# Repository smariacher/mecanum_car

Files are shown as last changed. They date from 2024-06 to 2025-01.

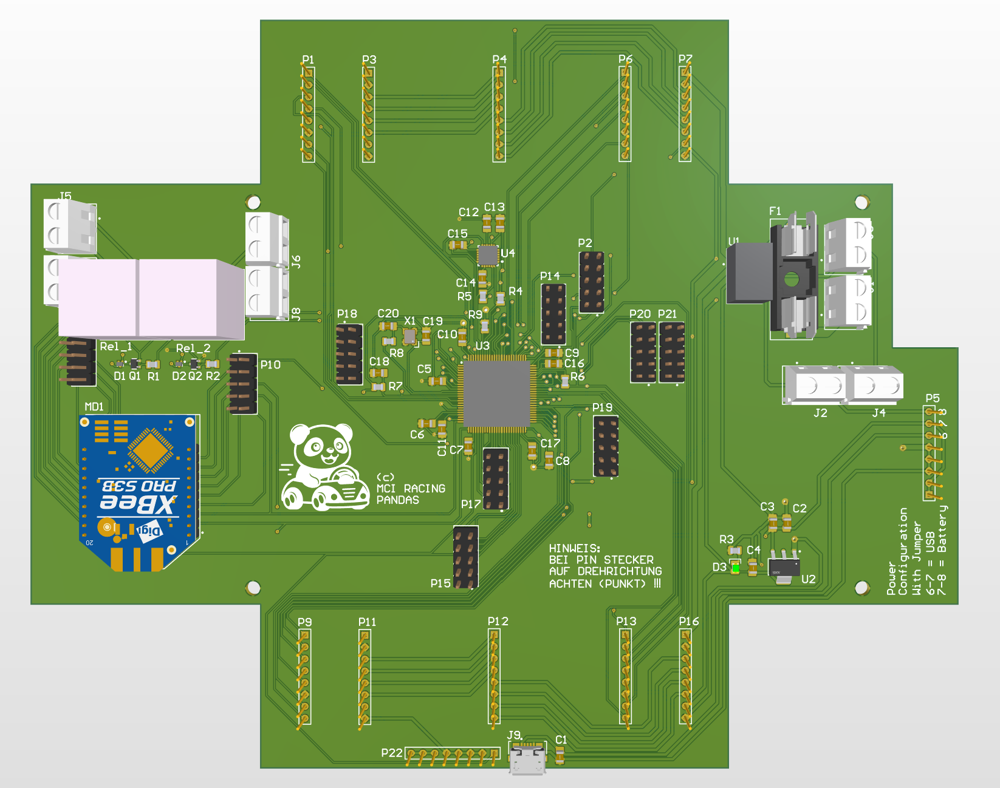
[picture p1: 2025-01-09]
Schematics/mecanum_car_2D.png

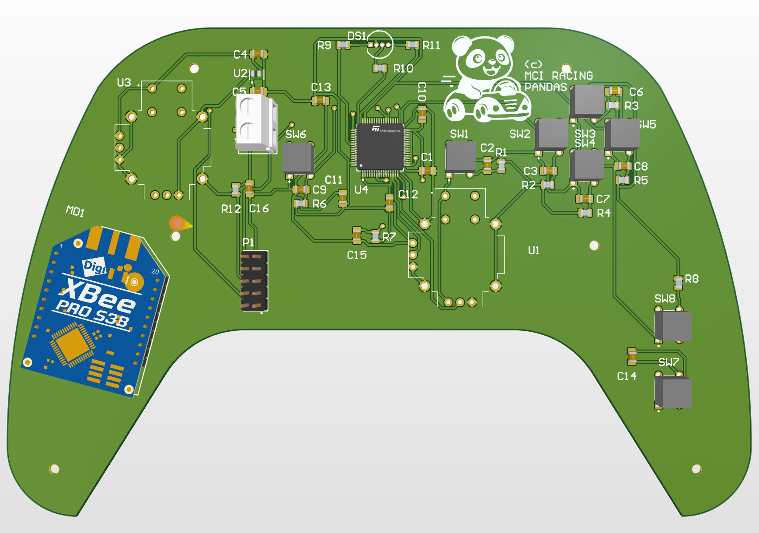
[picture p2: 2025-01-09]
Schematics/mecanum_car_controller_2D.png

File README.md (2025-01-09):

Mecanum Car Project

This repository contains all files and documentation related to the Mecanum Car, developed over two semesters (4th and 5th semester) as part of the Bachelor's degree program in Mechatronics Design & Innovation. The goal of the project was to design, implement, and test a fully functional Mecanum Car that meets both mechanical and electronic requirements.
Project Overview

The project's objective was to develop a functional Mecanum Car with omnidirectional movement capabilities. The focus was on mechanical design, electronic development, and software integration. The work spanned two semesters to allow iterative improvement and extension.
Key Features
Mechanical Design

    Lightweight and robust aluminum chassis for high durability and stability.
    Protective housing for all electronic components.
    Use of Mecanum wheels for omnidirectional movement.

Electronic System

    Power supply via a Makita power drill battery with an integrated voltage converter.
    Control unit based on an STM32F401VET6 microcontroller, offering sufficient reserves for future expansions.
    Integration of a gyro sensor (MPU6050) for acceleration data acquisition.
    Communication modules (XBee, infrared receiver) for future remote control options.
    Wiring of LEDs for front (white) and rear (red) lighting.

Software

    Control via Xbox controller.
    Debugging functionalities through hardware buttons.
    Modular programming of basic functions with potential for further extension.

Extensions

    Design and production of a custom controller PCB.
    Installation of a fan for cooling the PCB and motor drivers.
    Wiring and mounting of LEDs for vehicle lighting.

Repository Contents

    Mechanical Designs: CAD files of vehicle components (base plate, motor mounts, bumpers, etc.).
    Electronics: Schematics and PCB layouts created with Altium Designer.
    Firmware: Control software for the Mecanum Car, written in C++ for the STM32 microcontroller.
    Documentation: Final reports, technical specifications, and user manuals.

Getting Started
Prerequisites

    Development Environment:
        Altium Designer for PCB design.
        Visual Studio Code for firmware development.
    Hardware:
        Mecanum wheels, stepper motors, Makita battery, STM32 microcontroller, gyro sensor, and other components.

Installation

    Clone the repository:

    git clone https://github.com/smariacher/mecanum_car.git

    Open the project files in the corresponding software tools.

    Compile the firmware using the STM32 development environment.

Current Status

    Mechanics: The chassis has been fully implemented and functions flawlessly.
    Electronics: The PCB and motor control systems are fully operational.
    Software: Basic motion functionalities have been implemented; advanced features are under development.

Future Work

    Optimization of motor drivers for improved performance.
    Integration of a display for sensor data visualization.
    Expansion of automation and control functionalities.

Contributors

    Julian Fritzer
    Patrick Monthaler
    Simon Mariacher

## Source code
#### General Overview
Inside the `source_code` folder you can find the main code, the python controller and the example folder. The main code is meant to be flashed to the car and is the current working version. The python controller can be used to control the car via a computer using for example an Xbox-Controller or just keyboard inputs. Inside the `examples` folder you can find examples for XBEE-connection to the car, driving the stepper motors and more. There is also the old source code 

#### Main source code
The main source code has been thoroughly documented and can be flashed to the car via the exposed USB-B port on the side. For this you will need `Platform IO` in `Visual Studio Code`. 

#### Python Controller
To use the python controller, you will need to connect an XBEE via USB to your PC and configure the script to use the right COM port. You will also need to install `pygame`. When connecting a controller the code will automatically detect it when starting up and use the controller as input. When no controller is connected it will use the keyboard buttons WASD+EQ for movement and f+b for front and backlight respectively. The space bar is set to be used as an emergency stop function, where all motors will be disabled (meaning the will move freely) so that the car comes to a smooth stop. After emergency stopping you have to reset the car via the connected external button. Using a controller the car is moved through both analog sticks, and the A-Button is used as emergency stop (when using a XBOX-Controller).

#### Wireless protocol
The car's controller listens to UART2 which is connected to the XBEE. On receiving a message an interrupt function is called, which either changes the wheel speeds, toggles front or backlight or intitiates emergency stop. The message protocol to controll the wheel speeds is simple and consists of 20 characters, 5 for each wheel where the step frequency for the wheel is defined. As an example you can send a message using a tool like `PuTTY` and send `01000010000100001000` which will move every wheel at 1000 speed. Of course this protocol is limited to a max speed of 99999 or -9999. This should be upgraded later on.

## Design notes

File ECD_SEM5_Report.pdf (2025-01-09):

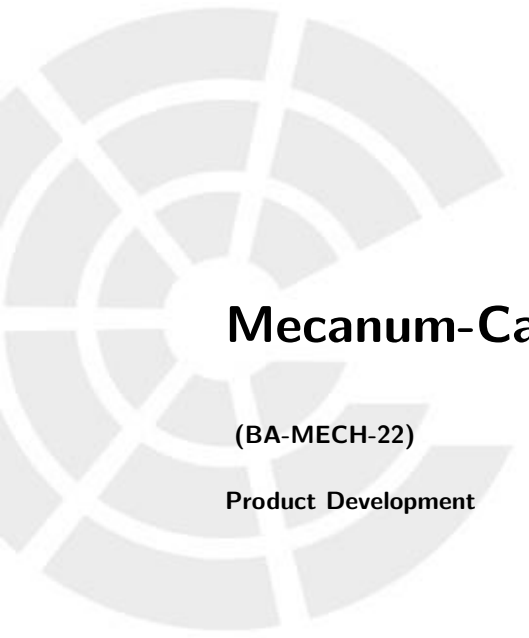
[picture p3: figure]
(BA-MECH-22); Product Development

# Mecanum-Car Report 5.Semester

Bachelor - Mechatronik Design & Innovation

### 5. Semester

Lektor: Matthias Gfall

Gruppe: BA-MECH-22

Autoren: Julian Fritzer, Patrick Monthaler, Simon Mariacher

### 9. Januar 2025

# Inhaltsverzeichnis

1 Abstract | 1
2 Introduction | 1
3 Equipment and Tools | 2
4 Project Objectives | 2
5 Methodology | 3
6 Discussion | 5
7 Conclusion and Future Work | 5
Abbildungsverzeichnis | III
Literaturverzeichnis | IV

II

2 INTRODUCTION

# 1 Abstract

This report presents the development of a Mecanum-Car over two semesters as part of the Bachelor’s program in Mechatronics Design and Innovation. The project combines mechanical design, electronic systems, and software integration to create a fully functional car with omnidirectional movement capabilities. The following sections detail the objectives, methods, and results, highlighting challenges and future potential for optimization.

# 2 Introduction

The Mecanum-Car project 2.1 was undertaken during the 4th and 5th semesters to integrate theoretical and practical aspects of mechatronic systems. The car uses Mecanum wheels to achieve omnidirectional movement, enabling precise control in confined spaces. The project included mechanical design, electronic system development, and software integration. This report documents the design process, implementation steps, and outcomes.

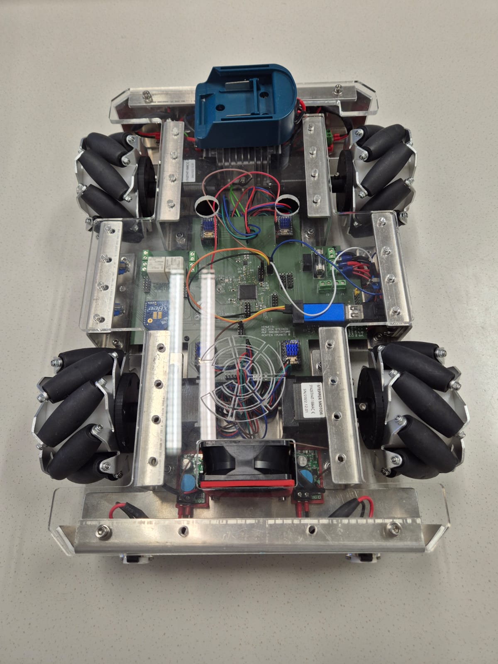
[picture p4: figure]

Abbildung 2.1: Robot with Mecanum wheels

4 PROJECT OBJECTIVES

# 3 Equipment and Tools

### 3.1 MECHANICAL COMPONENTS

- Lightweight aluminum chassis for durability and stability.
- Mecanum wheels for omnidirectional movement.
- Protective housing for electronic components.
- Air cooling system for the circuit board and motor drivers

### 3.2 ELECTRONIC COMPONENTS

- STM32F401VET6 microcontroller for control unit.
- Makita power drill battery with integrated voltage converter.
- Gyro sensor (MPU6050) for acceleration data acquisition.
- Communication modules: XBee.
- LEDs for front (white) and rear (red) lighting.

### 3.3 SOFTWARE TOOLS

- Altium Designer for PCB design.
- PlatformIO with Visual Studio Code for firmware development.
- Python and Pygame for external controller.

# 4 Project Objectives

The primary goal was to develop a fully functional Mecanum-Car with the following key features:

- Achieve omnidirectional movement through precise motor control.
- Implement a power supply system based on a Makita battery.
- Develop a custom PCB for motor control and integrate additional components like LEDs and fans.
- Enable control via an Xbox controller, a PC, and a custom-made controller, and provide debugging functionality through hardware buttons.

5 METHODOLOGY

# 5 Methodology

### 5.1 MECHANICAL DESIGN

The chassis was designed to be lightweight yet robust. Aluminum was chosen for its strength-to-weight ratio. A protective housing was included to safeguard the electronics from external damage.

Additionally, an appealing Plexiglas cover featuring an MCI logo was installed to provide a clear view of the circuit board and the internal components of the robot, enhancing its aesthetic appeal.

A fan was mounted at the front of the vehicle to ensure adequate cooling of the electronic components??.

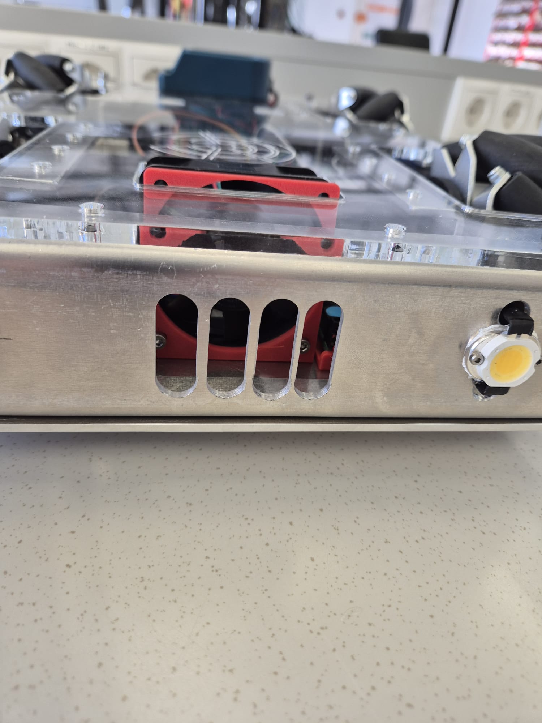
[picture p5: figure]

Abbildung 5.1: Air cooling

Mounts for controlling the front and rear LEDs were also designed and manufactured using a 3D printer. Environmentally friendly PLA material was used for this purpose ??.

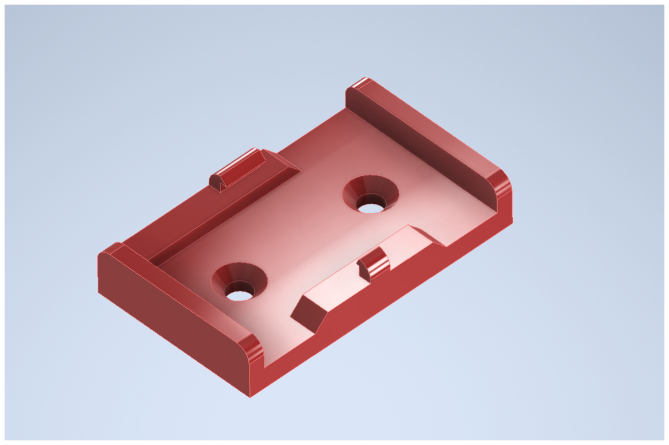
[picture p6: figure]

Abbildung 5.2: LED control fixture

5.2 Electronic System | 5 METHODOLOGY

### 5.2 ELECTRONIC SYSTEM

The control unit was based on the STM32F401VET6 microcontroller, offering sufficient capacity for future expansions. A Makita battery provided the primary power supply, ensuring reliable performance. Communication modules (XBee and infrared receiver) were integrated for wireless control. Cooling systems, including a fan, were added to maintain component performance.

The entire project was extended with a custom-designed controller that utilizes XBEE transmission. The controller is powered by three AAA batteries. The design was carefully crafted to ensure both ergonomic handling and a familiar look and feel, resembling a traditional console controller.


Abbildung 5.3: Mecanum car controller

The entire vehicle was rewired and enhanced with front and rear LEDs, including their corresponding control systems.

### 5.3 SOFTWARE DEVELOPMENT

Firmware was written in C++ and flashed onto the microcontroller using PlatformIO. Python scripts enabled external control via an Xbox controller. The communication protocol used UART2 to handle motor speed adjustments, lighting toggling, and emergency stops. Debugging functionalities were implemented via hardware buttons.

7 CONCLUSION AND FUTURE WORK

# 6 Discussion

The project highlighted the importance of iterative design and testing. While most objectives were achieved, certain challenges, such as optimizing motor driver performance, remain. The modular design allows for future enhancements, including sensor integration and advanced automation features.

Unfortunately, during the prototype development, a short circuit damaged the microcontroller. However, lessons were learned from this mistake. A new microcontroller was installed, and a complete circuit board diagnosis was performed, resulting in the vehicle’s control board being fully operational again.

# 7 Conclusion and Future Work

The Mecanum-Car project successfully combined mechanical, electronic, and software systems to create a functional prototype. Future improvements could focus on:

- Optimizing motor driver performance for higher efficiency.
- Integrating additional sensors for autonomous operation.
- Developing a display for real-time sensor data visualization.

Our prototype was also showcased during an internal MCI presentation, which turned out to be a great success. This highlights that the project was not only successful but also brought us immense joy. Furthermore, it is intended to serve as learning material for future students.

All data can be accessed via the following link: https://github.com/smariacher/mecanum_car

Abbildungsverzeichnis | VERZEICHNISSE

# Abbildungsverzeichnis

2.1 Robot with Mecanum wheels | | 1
5.1 Air cooling | | | 3
5.2 LED control fixture | | 3
5.3 Mecanum car controller | | 4

III

Literaturverzeichnis | VERZEICHNISSE

# Literaturverzeichnis

IV

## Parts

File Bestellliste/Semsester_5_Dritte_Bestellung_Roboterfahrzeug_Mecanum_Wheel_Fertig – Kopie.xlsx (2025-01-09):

 | Externe Teile
Pos. | Distributor Art. Nr. | Manufacturer Nr. | Manufacturer | Distributor | Description | Designator | Qty. | Price | Total Price | Value-added tax | Link
1 | 2010-02-02 | 4262375690033 | Bauer United | Bauer United | DC DC 8-40V zu 12V 10A |  | 1 | €45.23 | 45.23 € | incl. | https://bauer-united.com/products/dc-dc-8-40v-zu-12v-10a-spannungswandler
 |  |  |  |  |  |  |  | Summe | €45.23

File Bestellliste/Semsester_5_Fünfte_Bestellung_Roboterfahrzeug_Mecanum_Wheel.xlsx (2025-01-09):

 | Externe Teile
Pos. | Distributor Art. Nr. | Manufacturer Nr. | Manufacturer | Distributor | Description | Designator | Qty. | Price | Total Price | Value-added tax | Link
1 | 511-STM32F401VET6 | STM32F401VET6 | STMicroelectronics | Mouser | Mikrocontroller | U | 2 | €7.91 | 15.82 | incl. | https://www.mouser.de/ProductDetail/STMicroelectronics/STM32F401VET6?qs=s5SkPsIz109zpSHaICJY0A%3D%3D
2 | 926-LM1117MPX3.3NOPB | LM1117MPX-3.3/NOPB | Texas Instruments | Mouser | LDO Spannungs-Regulator | U2 | 2 | €1.02 | 2.04 € | incl. | https://www.mouser.de/ProductDetail/Texas-Instruments/LM1117MPX-3.3-NOPB?qs=X1J7HmVL2ZHRbBIxXi4utg%3D%3D
 |  |  |  |  |  |  |  | Summe | €17.86
1 | 595-TPSM828214SILR | TPSM828214SILR | Texas Instruments | Mouser | Schaltspannungsregler | U | 1 | €2.33 |  | incl | https://www.mouser.at/ProductDetail/Texas-Instruments/TPSM828214SILR?qs=iLbezkQI%252BsibRGaNc1MtTA%3D%3D
2 | 511-STM32F091RCT6 | STM32F091RCT6

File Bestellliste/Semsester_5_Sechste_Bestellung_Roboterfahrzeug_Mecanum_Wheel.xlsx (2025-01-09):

 | Interne Teile
Pos. | Distributor Art. Nr. | Manufacturer Nr. | Manufacturer | Distributor | Description | Designator | Qty. | Price | Total Price | Value-added tax | Link
1 | 595-TPSM828214SILR | TPSM828214SILR | Texas Instruments | Mouser | Schaltspannungsregler | U | 1 | €2.33 | €2.33 | incl | https://www.mouser.at/ProductDetail/Texas-Instruments/TPSM828214SILR?qs=iLbezkQI%252BsibRGaNc1MtTA%3D%3D
2 | 511-STM32F091RCT6 | STM32F091RCT6 | STM | Mouser | Microcontroller |  | 1 | €5.42 | €5.42 | incl | https://www.mouser.at/ProductDetail/STMicroelectronics/STM32F091RCT6?qs=ClYTdQWm4hDCc82GnPpqOQ%3D%3D
3 | 571-5-534998-5 | 5-534998-5 | TE Connectivity | Mouser | Kabelgehäuse |  | 2 | €1.97 | €3.94 | incl | https://www.mouser.at/ProductDetail/TE-Connectivity/5-534998-5?qs=xDp7PGUNC%252Bs6ZU%2FXKidt5w%3D%3D
4 | 1311370 - 62 | FHS43S10G | econ | Conrad | Buchsenleiste 1 Reihe 10 Pins 2mm | P | 4 | €0.81 | €3.24 | incl. | https://www.conrad.at/de/p/econ-connect-buchsenleiste-standard-anzahl-reihen-1-polzahl-je-reihe-10-fhs43s10g-1-st-1311370.html
5 | 604-WP154A43VBDZGWCA | WP154A4SEJ3VBDZGW/CA | Kingbright | Mouser | RGB LED |  | 2 | €1.81 | €3.62 | incl. | https://www.mouser.at/ProductDetail/Kingbright/WP154A4SEJ3VBDZGW-CA?qs=YCa%2FAAYMW01xRqZww6UuiQ%3D%3D
6 | 653-B3W-1050 | B3W-1050 | Omron Electronics | Mouser | Sensorschalter | S | 8 | €0.61 | €4.91 | incl | https://www.mouser.at/ProductDetail/Omron-Electronics/B3W-1050?qs=sQVrL4YZhsSNS5%2F0G96OcA%3D%3D
7 | 963-LMK212BBJ226MG-T | LMK212BBJ226MG-T | TAIYO YUDEN | Mouser | Kondensator 22uF |  | 10 | €0.10 | €0.96 | incl | https://www.mouser.at/ProductDetail/TAIYO-YUDEN/LMK212BBJ226MG-T?qs=Va%252BXcMGJzEt5r7CLFWWrQQ%3D%3D
8 | 474-COM-09032 | COM-09032 | SparkFun | Mouser | SparkFun Zubehör Thumb Joystick |  | 2 | €3.67 | €7.34 | incl | https://www.mouser.at/ProductDetail/SparkFun/COM-09032?qs=WyAARYrbSnb9u7eU4VaEfQ%3D%3D
9 | 810-CGA4J1X7R1E475KA | CGA4J1X7R1E475K125AE | TDK | Mouser | Kondensator 4,7 uF |  | 10 | €0.23 | €2.34 | incl. | https://www.mouser.at/ProductDetail/TDK/CGA4J1X7R1E475K125AE?qs=nQSIdc08i%252BfhTtI2X7XptA%3D%3D
10 | 589-BHF-3A3 | BHF-3A3 | Twin Industries | Mouser | Batteriegehäuse |  | 1 | €3.22 | €3.22 | incl. | https://www.mouser.at/ProductDetail/Twin-Industries/BHF-3A3?qs=HXFqYaX1Q2xp%252BBSp1724uQ%3D%3D
 |  |  |  |  |  |  |  |  | Total Sum
 |  |  |  |  |  |  |  |  | €37.32

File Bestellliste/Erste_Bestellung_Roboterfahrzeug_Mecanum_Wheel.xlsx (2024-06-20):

Pos. | Distributor Art. Nr. | Manufacturer Nr. | Manufacturer | Distributor | Description | Designator | Qty. | Price | Total Price | Value-added tax | Link
1 | 1597325-62 | NEMA-17-01 | Joy-it | conrad | Schrittmotor | M1-4 | 4 | 28.9900 € | 115.9600 € | incl. | https://www.conrad.at/de/p/joy-it-schrittmotor-nema-17-01-nema-17-01-0-4-nm-1-68-a-wellen-durchmesser-5-mm-1597325.html
2 | 22081 | 14162 | Nexus Robot | noDNA | Mecanum Wheels Satz |  | 1 | 135.6600 € | 135.6600 € | incl. | https://www.nodna.de/Nexus-Robot-Allseitenrad-Rechts-4-Zoll-100mm-Aluminium-Rundlaufrad-Mecanum-Wheel-basic-14162-Set-2-x-Links-2-x-Rechts
3 | BIQU-ZZB000295 | ZZB000295 | BIGTREETECH | 3djake | Steper Motor Driver TMC2208 | U1-4 | 3 | 5.9900 € | 17.9700 € | incl. | https://www.3djake.at/bigtreetech/stepper-motor-driver
4 | 1616245 - 62 | ST1099 | Iduino | conrad | Ultraschallsensor | E1-2 | 2 | 3.4900 € | 6.9800 € | incl. | https://www.conrad.at/de/p/iduino-st1099-ultraschallsensor-1-st-1616245.html#productDownloads
5 | 1516595 - 62 | 169 | adafruit | conrad | Servomotor | M5 | 1 | 15.9900 € | 15.9900 € | incl. | https://www.conrad.at/de/p/adafruit-169-servomotor-1-st-1516595.html
6
 |  |  |  |  |  |  | SUM | 190.1200 € | 292.5600 €
Distributor
Mouser
DigiKey
reichelt
Conrad
Farnell
ect.

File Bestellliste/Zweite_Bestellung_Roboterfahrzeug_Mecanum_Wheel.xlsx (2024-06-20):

 | Externe Teile
Pos. | Distributor Art. Nr. | Manufacturer Nr. | Manufacturer | Distributor | Description | Designator | Qty. | Price | Total Price | Value-added tax | Link
1 | BIQU-ZZB000316 | ZZB000315 | BIGTREETECH | 3djake | Steper Motor Driver TMC2209 | U1-2 | 3 | €6.99 | 20.9700 € | incl. | https://www.3djake.at/bigtreetech/stepper-motor-driver
2 | 888-XB24CAPIT-001 | XB24CAPIT-001 | DIGI | Mouser | XBEE | MD1 | 2 | 27.28 € | 54.56 € | incl. | https://www.mouser.de/ProductDetail/Digi/XB24CAPIT-001?qs=%2FPVulymFwT3%2F4LVtV76gSw%3D%3D
3 | 782-TSOP38238 | TSOP38238 | Vishay Semiconductors | Mouser | Infrarot-Receiver |  | 1 | 0.86 € | 0.86 € | incl. | https://www.mouser.de/ProductDetail/Vishay-Semiconductors/TSOP38238?qs=RzxYCzJDjPVjpHVZS582Ng%3D%3D
4 | 780-ASADPUSBCTOXBEE | AS-ADP-USBC-TO-XBEE | ArduSimple | Mouser | XBEE Adapter USB-C |  | 1 | 21.53 € | 21.53 € | incl. | https://www.mouser.de/ProductDetail/ArduSimple/AS-ADP-USBC-TO-XBEE?qs=amGC7iS6iy8NI294ej0eBQ%3D%3D
5 | 701280 - 62 | 701280 | TRU Components | Conrad | Schalter | S1-2 | 2 | 6.99 € | 13.98 € | incl. | https://www.conrad.at/de/p/tru-components-701280-gq-16f-s-vandalismusgeschuetzter-drucktaster-48-v-dc-2-a-1-x-aus-ein-tastend-ip65-1-st-701280.html
6 | 2010-02-02 | 4262375690033 | Bauer United | Bauer United | DC DC 8-40V zu 12V 10A |  | 1 | €45.23 | 45.23 € | incl. | https://bauer-united.com/products/dc-dc-8-40v-zu-12v-10a-spannungswandler
 |  |  |  |  |  |  |  | Summe | 157.1350 €
 | Teile Platine
Pos. | Distributor Art. Nr. | Manufacturer Nr. | Manufacturer | Distributor | Description | Designator | Qty. | Price | Total Price | Value-added tax
1 | 282836-2 | 282836-2 | TE Connectivity (https://www.mouser.de/manufacturer/phoenix-contact/) | Mouser | Schraubklemmen | P | 10 | €0.56 | 5.58 € | incl. | https://www.mouser.de/ProductDetail/TE-Connectivity/282836-2?qs=A%252Bip%252BNCYi6Ohx9vaQ1l4dg%3D%3D
2 | 576-64600001223 | 64600001223 | Littelfuse (https://www.mouser.de/manufacturer/littelfuse/) | Mouser | Sicherungshalter | F1 | 1 | €0.78 | 0.78 € | incl. | https://www.mouser.de/ProductDetail/Littelfuse/64600001223?qs=up76HT6PtJjfTS5uVso6wg%3D%3D
3 | 538-47346-0001 | 473460001 | Molex | Mouser | USB-Stecker MICRO USB | J | 1 | €1.08 | 1.08 € | incl. | https://www.mouser.de/ProductDetail/Molex/47346-0001?qs=c2CV6XM0DweJBWaSeyWeCw%3D%3D
4 | 926-LM1117MPX3.3NOPB | LM1117MPX-3.3/NOPB | Texas Instruments | Mouser | LDO Spannungs-Regulator | U2 | 1 | €1.02 | 1.02 € | incl. | https://www.mouser.de/ProductDetail/Texas-Instruments/LM1117MPX-3.3-NOPB?qs=X1J7HmVL2ZHRbBIxXi4utg%3D%3D
5 | 604-APHCM2012ZGC-F01 | APHCM2012ZGC-F01 | Kingbright | Mouser | LED Grün | D3 | 1 | €0.65 | 0.65 € | incl. | https://www.mouser.de/ProductDetail/Kingbright/APHCM2012ZGC-F01?qs=f499HRGa1RlJsLxscn0ySA%3D%3D
6 | 511-STM32F401VET6 | STM32F401VET6 | STMicroelectronics | Mouser | Mikrocontroller | U | 1 | €7.91 | 7.91 | incl. | https://www.mouser.de/ProductDetail/STMicroelectronics/STM32F401VET6?qs=s5SkPsIz109zpSHaICJY0A%3D%3D
7 | 732-TX325-24F15X-AC3 | TSX-3225 24.0000MF15X-AC3 | Epson Timing | Mouser | Crystal SMD 24MHz | X1 | 1 | €0.78 | 0.78 € | incl. | https://www.mouser.de/ProductDetail/Epson-Timing/TSX-3225-24.0000MF15X-AC3?qs=tC2qD9afNgpYJ9VgPl1%2FUg%3D%3D
8 | 495-TSR-1-2450 | TSR 1-2450 | TRACO Power | Mouser | DC-DC-WANDLER | U1 | 1 | €5.14 | 5.14 € | incl. | https://www.mouser.de/ProductDetail/TRACO-Power/TSR-1-2450?qs=ckJk83FOD0XFKqda0Mzkgw%3D%3D
9 | 2139312 - 62 | TC-2506421 | TRUE Components | Conrad | Buchsenleiste 1 Reihe 8 Pins | P | 12 | €1.49 | €17.88 | incl. | https://www.conrad.at/de/p/tru-components-buchsenleiste-standard-anzahl-reihen-1-polzahl-je-reihe-8-tc-2506421-1-st-2139312.html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
10 | 742235 - 62 | 10120504 | BKL Electronic | Conrad | Stiftleiste 1 Reihe 8 Pins | P | 4 | €0.41 | 1.64 € | incl. | https://www.conrad.at/de/p/bkl-electronic-stiftleiste-standard-anzahl-reihen-1-polzahl-je-reihe-8-10120504-1-st-742235.html
11 | 710-61301021121 | 61301021121 | Wurth Elektronik | Mouser | Stiftleiste 2 Reihe 10 Pins | P2 | 12 | €1.03 | 12.36 € | incl. | https://www.mouser.de/ProductDetail/Wurth-Elektronik/61301021121?qs=ZtY9WdtwX5612K9FdDCZCA%3D%3D
12 | 771-BC846BW-T/R | BC846BW,115 | Nexperia | Mouser | Bipolartransistoren | Q1-Q2 | 2 | €0.14 | 0.28 € | incl. | https://www.mouser.de/ProductDetail/Nexperia/BC846BW115?qs=me8TqzrmIYXeHaJTKQ9DIQ%3D%3D
13 | 571-9-1415356-1 | 9-1415356-1 | TE Connectivity / P&B | Mouser | Relai | R1-2 | 2 | €2.19 | 4.38 € | incl. | https://www.mouser.de/ProductDetail/TE-Connectivity-PB/9-1415356-1?qs=y33ekyoD0SqBQ0O9kVi%2FHQ%3D%3D
14 | 1311370 - 62 | FHS43S10G | econ | Conrad | Buchsenleiste 1 Reihe 10 Pins 2mm | P | 4 | €0.81 | 3.24 | incl. | https://www.conrad.at/de/p/econ-connect-buchsenleiste-standard-anzahl-reihen-1-polzahl-je-reihe-10-fhs43s10g-1-st-1311370.html
15 | 410-MPU-6050 | MPU-6050 | TDK InvenSense | Mouser | Messeinheiten | U4 | 1 | €7.99 | 7.99 € | incl. | https://www.mouser.de/ProductDetail/TDK-InvenSense/MPU-6050?qs=u4fy%2FsgLU9O14B5JgyQFvg%3D%3D
 |  |  |  |  |  |  |  | Summe | 70.71 €
 | Klein Material Platine
Pos. | Distributor Art. Nr. | Manufacturer Nr. | Manufacturer | Distributor | Description | Designator | Qty. | Price | Total Price | Value-added tax
1 | 80-C0805C226K9PACTU | C0805C226K9PACTU | KEMET | Mouser | Kondensator 22uF | C | 2 | 0.33 € | 0.65 € | incl. | https://www.mouser.de/ProductDetail/KEMET/C0805C226K9PACTU?qs=CmJlwSR1kv6i2XEByn7wWw%3D%3D
2 | 80-C0805C225K4R3123 | C0805C225K4RAC3123 | KEMET | Mouser | Kondensator 2,2 uF | C | 2 | 0.28 € | 0.56 € | incl. | https://www.mouser.de/ProductDetail/KEMET/C0805C225K4RAC3123?qs=TJyCevD4CUGNcz2FRWNwVg%3D%3D
3 | 80-C0805C100JDGAUTO | C0805C100JDGACAUTO | KEMET | Mouser | Kondensator 10pF | C | 2 | 0.40 € | 0.80 € | incl. | https://www.mouser.de/ProductDetail/KEMET/C0805C100JDGACAUTO?qs=HBWAp0VN4Rjpqlt%2F5qjk4w%3D%3D
4 | 80-C0805R104J5RACTU | C0805R104J5RACTU | KEMET | Mouser | Kondensator 100nF | C | 12 | 1.83 € | 21.96 € | incl. Ab 10Stück | https://www.mouser.de/ProductDetail/KEMET/C0805R104J5RACTU
5 | 863-NSVBAT54M3T5G | NSVBAT54M3T5G | onsemi | Mouser | Diode | D1-D2 | 2 | 0.21 € | 0.42 € | incl. | https://www.mouser.de/ProductDetail/onsemi/NSVBAT54M3T5G?qs=abmNkq9no6DkGD4o8NjPMA%3D%3D
6 | 80-C0805X103J5RACTU | C0805X103J5RACTU | KEMET | Mouser | Kondensator 10nF | C13 | 1 | 0.45 € | 0.45 € | incl. | https://www.mouser.de/ProductDetail/KEMET/C0805X103J5RACTU
7 | 80-C0805C222F3G | C0805C222F3GACTU | KEMET | Mouser | Kondensator 2,2nF | C14 | 1 | 0.89 € | 0.89 € | incl. | https://www.mouser.de/ProductDetail/KEMET/C0805C222F3GACTU
 |  |  |  |  |  |  |  | Summe | 25.73 €
 |  |  |  |  |  |  |  | Totale Summe | €253.5770

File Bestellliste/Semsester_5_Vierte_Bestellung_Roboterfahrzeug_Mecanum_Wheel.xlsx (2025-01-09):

 | Externe Teile
Pos. | Distributor Art. Nr. | Manufacturer Nr. | Manufacturer | Distributor | Description | Designator | Qty. | Price | Total Price | Value-added tax | Link
1 | NO NF-A4X10 PWM | NF-A4X10 PWM | NOCTUA | Reichelt | Lüfter |  | 2 | €16.03 | 32.06 € | incl. | https://www.reichelt.at/at/de/shop/produkt/noctua_nf-a4x10_pwm_gehaeuseluefter_40_mm-316216
2 | N CCGL61010BK10 | CCGL61010BK10 | nedis | Reichelt | USB Kabel |  | 1 | €4.33 | 4.33 € | incl. | https://www.reichelt.at/at/de/shop/produkt/usb_3_0_kabel_a-stecker_a-buchse_1m_schwarz-386652
3 | CLIFF CP30207NM | CP30207NM | Cliff | Reichelt | USB-Adapter |  | 1 | €7.97 | 7.97 € | incl. | https://www.reichelt.at/at/de/shop/produkt/usb-adapter_ft_1_x_usb_2_0_b-buchse_1_x_usb_2_0_a-buchse-227651
 |  |  |  |  |  |  |  | Summe | €44.36

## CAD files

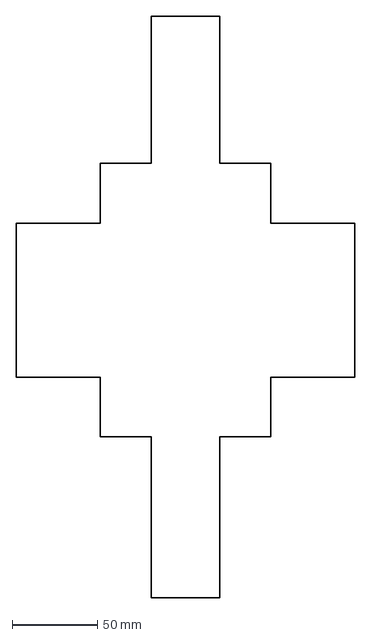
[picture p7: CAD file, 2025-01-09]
altium_source_data/mecanum_car/pcb_shape.dxf
198.0 x 340.0 mm

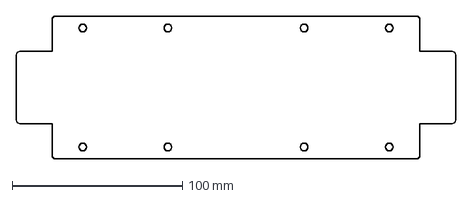
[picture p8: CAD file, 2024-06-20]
Inventor/Elektronische_Produktentwicklung_FF-Tank/Stossfänger.dxf
257.8 x 83.9 mm

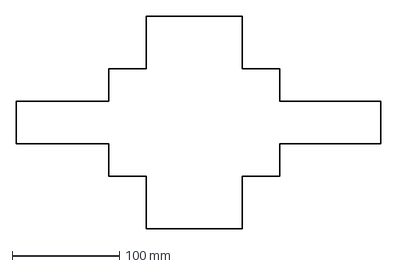
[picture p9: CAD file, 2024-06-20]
Inventor/Elektronische_Produktentwicklung_FF-Tank/Platine.dxf
340.0 x 198.0 mm

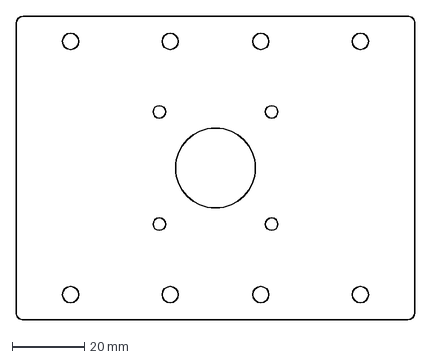
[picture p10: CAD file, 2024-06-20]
Inventor/Elektronische_Produktentwicklung_FF-Tank/Motorhalter.dxf
110.0 x 83.9 mm

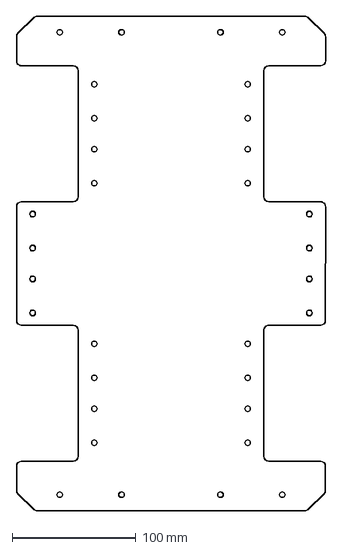
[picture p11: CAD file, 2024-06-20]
Inventor/Elektronische_Produktentwicklung_FF-Tank/Grundgehäuse.dxf
250.0 x 400.0 mm

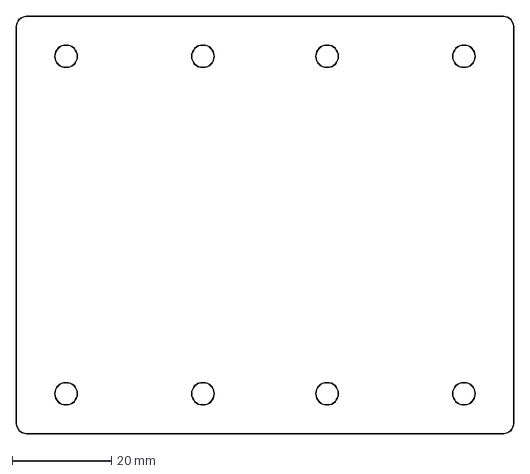
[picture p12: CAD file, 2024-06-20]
Inventor/Elektronische_Produktentwicklung_FF-Tank/Seitenteil.dxf
100.0 x 83.9 mm

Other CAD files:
Inventor/Elektronische_Produktentwicklung_FF-Tank/DCDC_Wandler.ipt
Inventor/Elektronische_Produktentwicklung_FF-Tank/Fahrgestell_Baugruppe_01.iam
Inventor/Elektronische_Produktentwicklung_FF-Tank/Fahrgestell_Baugruppe_01.idw
Inventor/Elektronische_Produktentwicklung_FF-Tank/Grundgehäuse_01.idw
Inventor/Elektronische_Produktentwicklung_FF-Tank/Grundgehäuse_01.ipt
Inventor/Elektronische_Produktentwicklung_FF-Tank/Halter_Lüfter.ipt
Inventor/Elektronische_Produktentwicklung_FF-Tank/Halter_Treiber_LED.ipt
Inventor/Elektronische_Produktentwicklung_FF-Tank/Halter_Treiber_LED_2.ipt
Inventor/Elektronische_Produktentwicklung_FF-Tank/Motor.ipt
Inventor/Elektronische_Produktentwicklung_FF-Tank/Motorhalter_02.idw
Inventor/Elektronische_Produktentwicklung_FF-Tank/Motorhalter_02.ipt
Inventor/Elektronische_Produktentwicklung_FF-Tank/OldVersions/Fahrgestell_Baugruppe_01.0001.idw
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

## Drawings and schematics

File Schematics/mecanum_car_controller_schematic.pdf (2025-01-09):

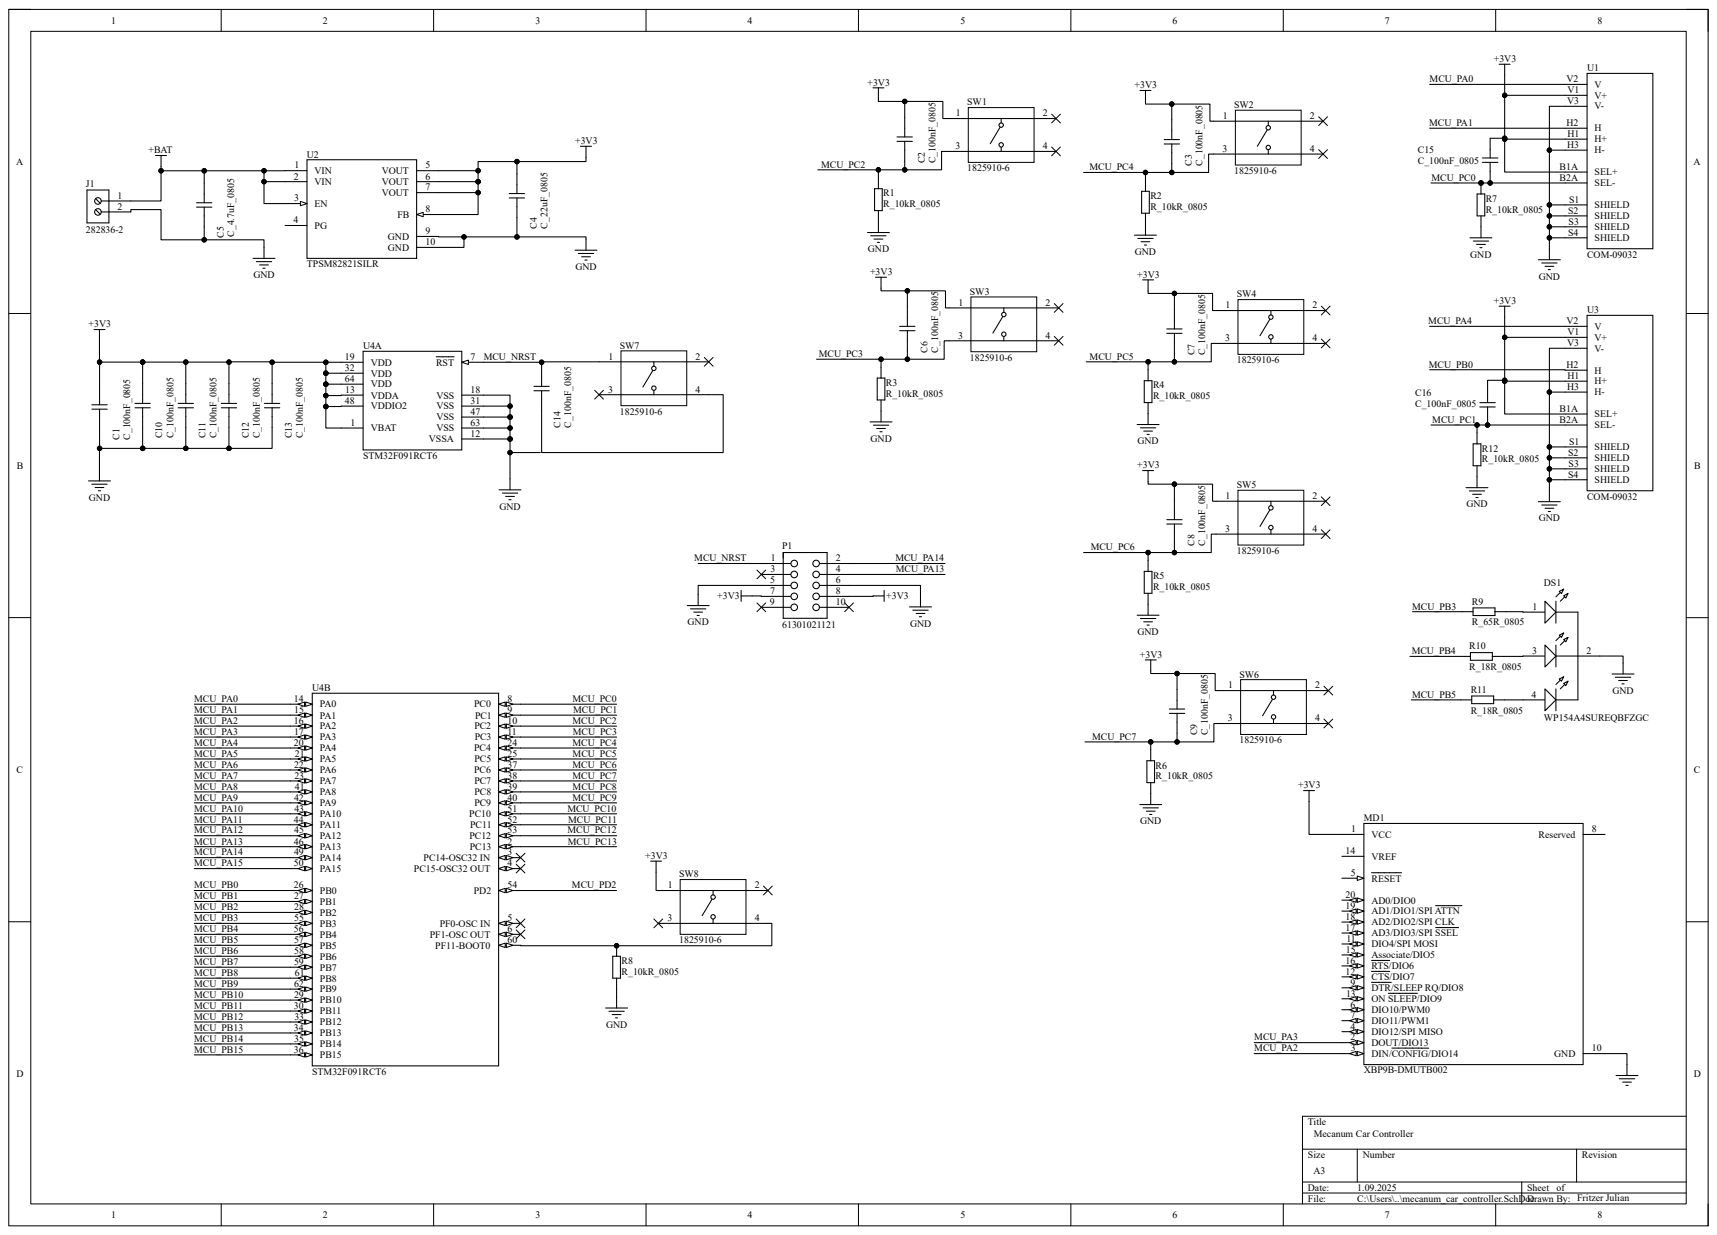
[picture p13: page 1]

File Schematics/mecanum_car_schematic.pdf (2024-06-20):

1 3 2

+5V1 3

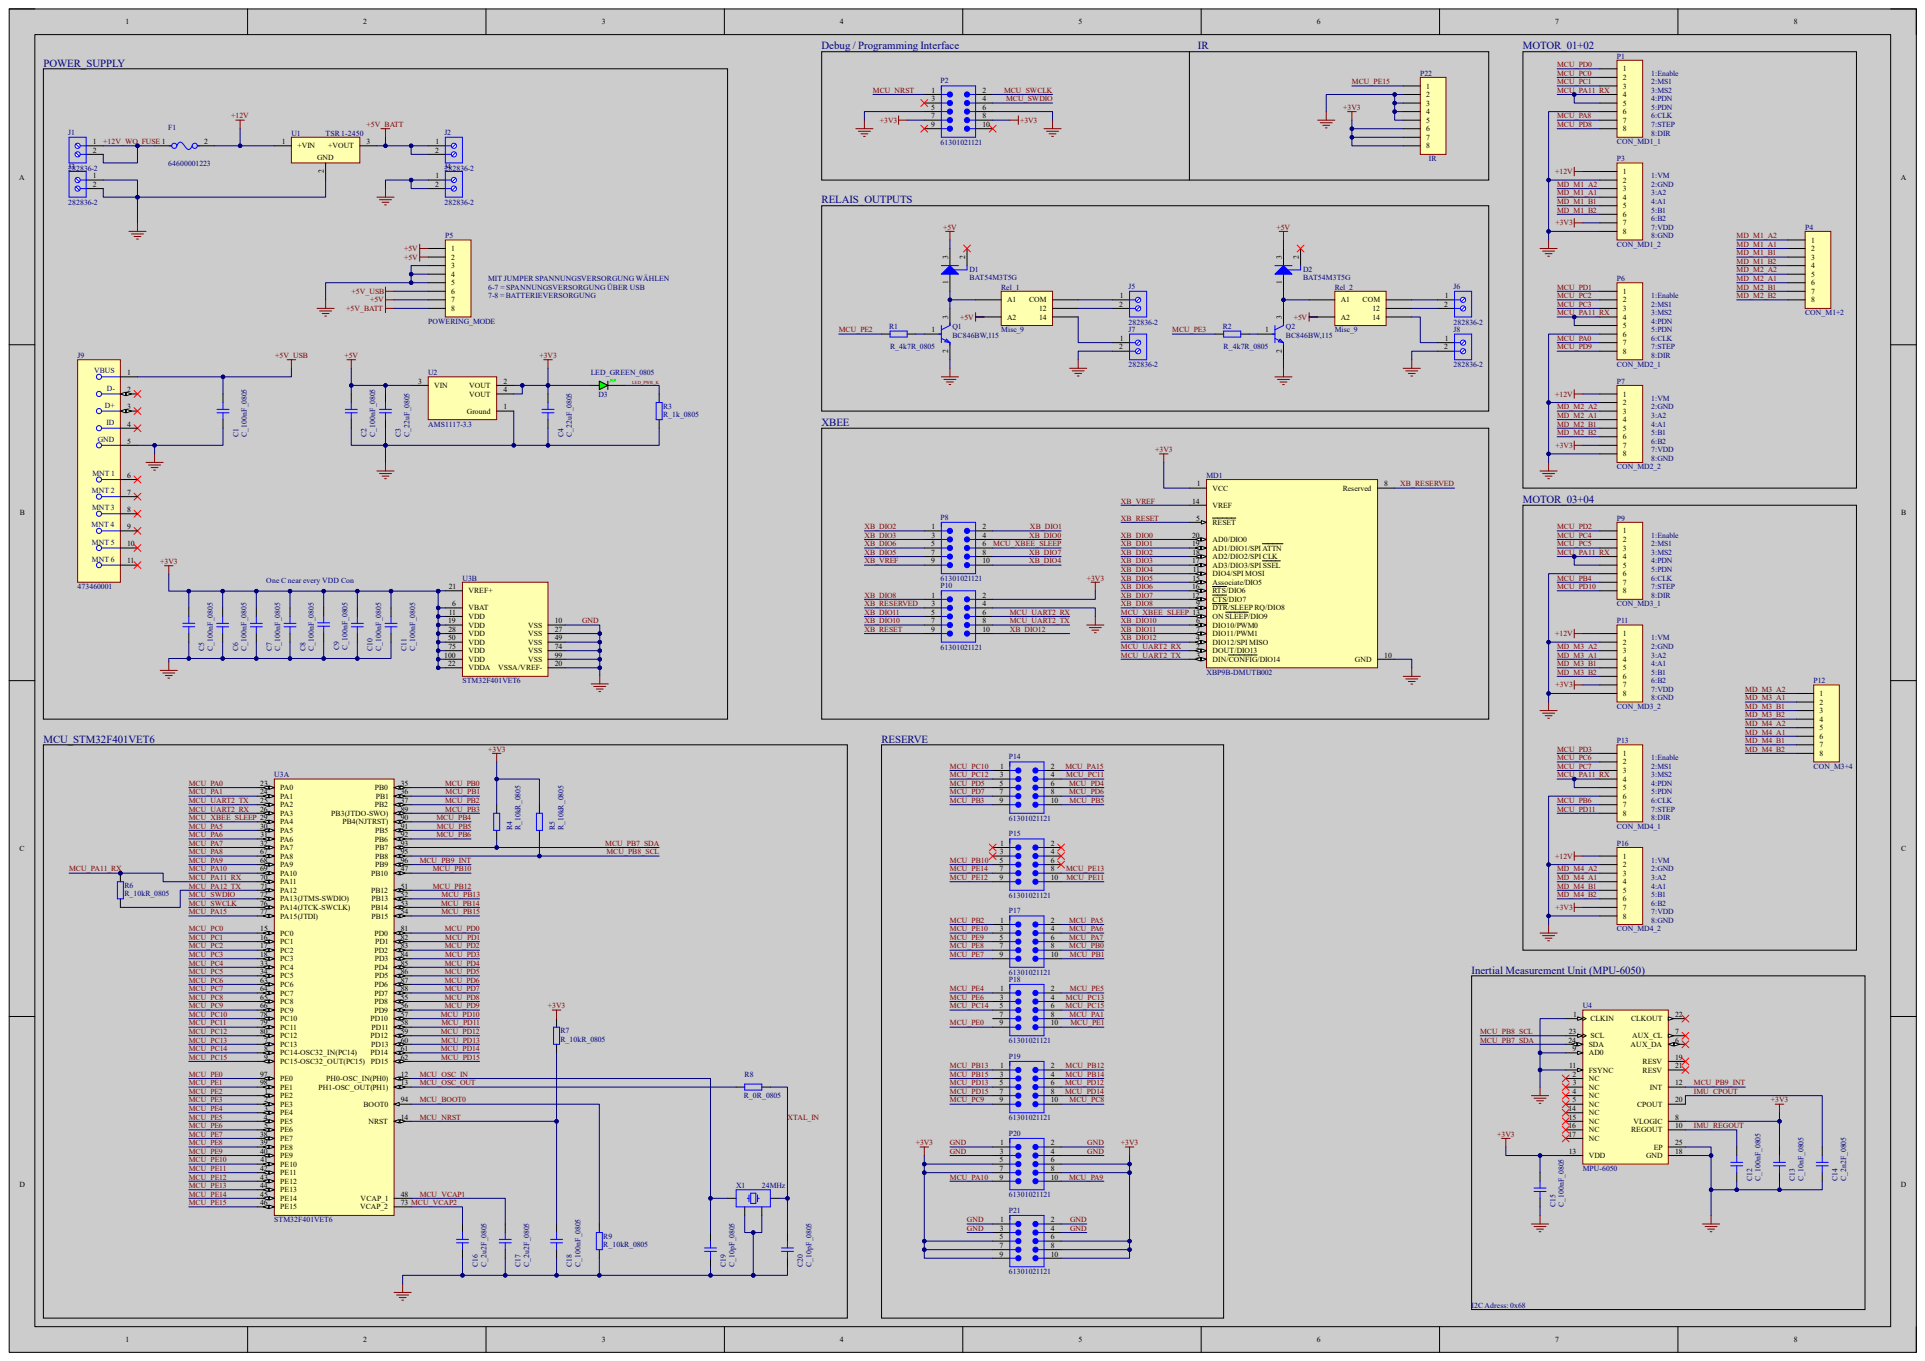
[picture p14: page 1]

MIT JUMPER SPANNUNGSVERSORGUNG WÄHLEN
6-7 = SPANNUNGSVERSORGUNG ÜBER USB
7-8 = BATTERIEVERSORGUNG

Inertial Measurement Unit (MPU-6050)

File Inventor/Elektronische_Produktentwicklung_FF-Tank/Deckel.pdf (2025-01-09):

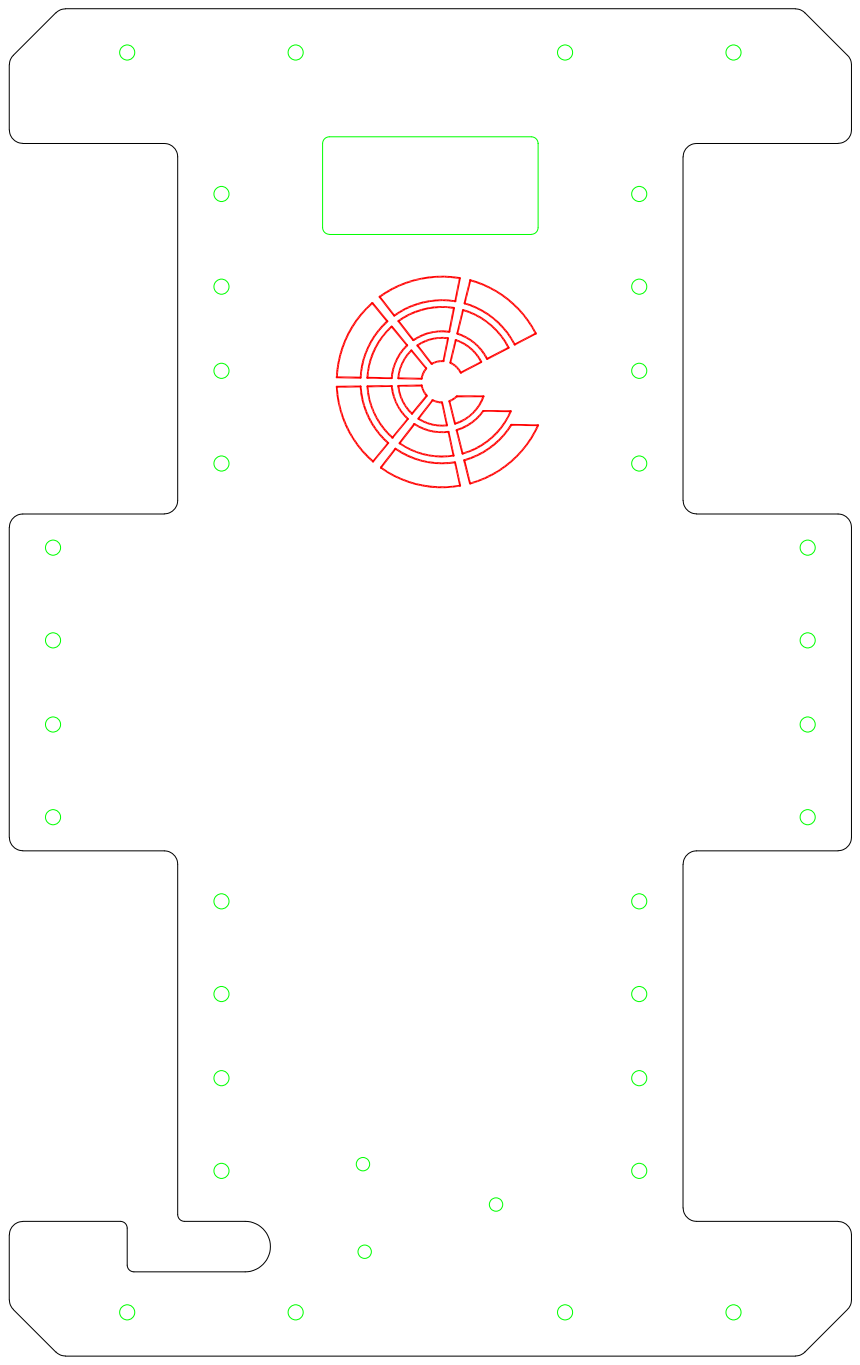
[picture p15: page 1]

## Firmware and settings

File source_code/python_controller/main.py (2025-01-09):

import pygame as pg
import sys
import serial
import time
import math

# VISUAL_MODE opens a window for speed debugging
VISUAL_MODE = False 

# Initialize pg
pg.init()

# Set up display
screen_width, screen_height = 300, 300
screen = pg.display.set_mode((screen_width, screen_height))
pg.display.set_caption("Robot Controller")

# Initialize the joystick module
pg.joystick.init()

# Check for joystick availability
joystick = None
if pg.joystick.get_count() > 0:
    joystick = pg.joystick.Joystick(0)
    joystick.init()
    print(f"Joystick name: {joystick.get_name()}")
else:
    print("No joystick connected. Using keyboard input.")

# Define some colors
BLACK = (0, 0, 0)
WHITE = (255, 255, 255)
RED = (255, 0, 0)
DARK_GREY = (100,100,100)

# Keyboard input handling function
def get_keyboard_input():
    x, y, turn = 0, 0, 0

    # Movement controls
    if pg.key.get_pressed()[pg.K_w]:
        y -= 1
    if pg.key.get_pressed()[pg.K_s]:
        y += 1
    if pg.key.get_pressed()[pg.K_a]:
        x -= 1
    if pg.key.get_pressed()[pg.K_d]:
        x += 1

    # Turning controls
    if pg.key.get_pressed()[pg.K_q]:
        turn -= 1
    if pg.key.get_pressed()[pg.K_e]:
        turn += 1

    return x, y, turn

# Function to draw the joystick axes
def draw_axes(screen, joystick):
    for i in range(2):
        axis_value = joystick.get_axis(i)
        bar_length = (axis_value + 1) * (screen_width / 4)
        bar_x = screen_width / 4
        bar_y = 50 + i * 50
        pg.draw.rect(screen, RED, [bar_x, bar_y, bar_length, 20])
        pg.draw.rect(screen, BLACK, [bar_x, bar_y, screen_width / 2, 20], 2)
        axis_label = f"Axis {i}: {axis_value:.2f}"
        font = pg.font.Font(None, 36)
        text = font.render(axis_label, True, WHITE)
        screen.blit(text, (bar_x + screen_width / 2 + 10, bar_y))

def draw_wheels(width, height, offset):
    pg.draw.rect(screen, DARK_GREY, [offset, offset, width, height])
    pg.draw.rect(screen, DARK_GREY, [screen_height - offset - width, offset, width, height])
    pg.draw.rect(screen, DARK_GREY, [offset, screen_height - offset - height, width, height])
    pg.draw.rect(screen, DARK_GREY, [screen_height - offset - width, screen_height - offset - height, width, height])

def draw_arrow(screen, start_pos, end_pos, color):
    arrow_width = 10
    arrow_head_length = 20

    # Calculate the direction vector
    direction = pg.math.Vector2(end_pos) - pg.math.Vector2(start_pos)
    length = direction.length()
    if length == 0:
        return

    direction = direction.normalize()

    # Calculate the points for the arrow head
    left = pg.math.Vector2(-direction.y, direction.x) * arrow_width
    right = pg.math.Vector2(direction.y, -direction.x) * arrow_width
    arrow_tip = pg.math.Vector2(end_pos)
    arrow_base = arrow_tip - direction * arrow_head_length

    # Draw the arrow line
    pg.draw.line(screen, color, start_pos, arrow_base, 2)

    # Draw the arrow head
    points = [arrow_tip, arrow_base + left, arrow_base + right]
    pg.draw.polygon(screen, color, points)    

def draw_speed_arrows(offset_x, offset_y, wheel_speed):
    multiplier = 0.5
    for i in range(4):
        wheel_speed[i] *= multiplier

    draw_arrow(screen, [offset_x, offset_y], [offset_x, offset_y + wheel_speed[0]], RED)
    draw_arrow(screen, [screen_width - offset_x, offset_y], [screen_width - offset_x, offset_y + wheel_speed[1]], RED)
    draw_arrow(screen, [offset_x, screen_height - offset_y], [offset_x, screen_height - offset_y + wheel_speed[2]], RED)
    draw_arrow(screen, [screen_width - offset_x, screen_height - offset_y], [screen_width - offset_x, screen_height - offset_y + wheel_speed[3]], RED)

def draw_direction(input_source, is_joystick=True):
    multiplier = 100
    if is_joystick:
        x = -input_source.get_axis(0)*multiplier
        y = -input_source.get_axis(1)*multiplier
    else:
        x, y, _ = input_source
        x *= multiplier
        y *= multiplier

    draw_arrow(screen, [screen_width/2, screen_height/2], [screen_width/2 + x, screen_height/2 + y], RED)

def get_wheel_speeds(input_source, is_joystick=True):
    speeds = [0,0,0,0]
    
    if is_joystick:
        x = -input_source.get_axis(0)*255
        y = -input_source.get_axis(1)*255
        turn = input_source.get_axis(2)*255
    else:
        x, y, turn = input_source
        x *= 300
        y *= 300
        turn *= 300

    clamp_x = 20
    clamp_y = 20
    clamp_turn = 20

    if turn < clamp_turn and turn > -clamp_turn:
        turn  = 0

    if x < clamp_x and x > -clamp_x:
        x = 0
    if y < clamp_y and y > -clamp_y:
        y = 0

    theta = math.atan2(y, x)
    power = math.hypot(x, y)

    sin = math.sin(theta - math.pi/4)
    cos = math.cos(theta - math.pi/4)
    this_max = max(abs(sin), abs(cos))

    if this_max == 0:
        this_max = 0.1

    speeds[0] = power * cos/this_max + turn
    speeds[1] = power * sin/this_max - turn
    speeds[2] = power * sin/this_max + turn
    speeds[3] = power * cos/this_max - turn

    return speeds

if VISUAL_MODE:
    try:
        while True:
            wheel_width = 120
            wheel_height = 200
            offset = 100

            # Handle events
            for event in pg.event.get():
                if event.type == pg.QUIT:
                    sys.exit()

            # Clear the screen
            screen.fill(BLACK)

            # Draw axes and speed based on input source
            if joystick:
                draw_axes(screen, joystick)
                wheel_speeds = get_wheel_speeds(joystick)
                draw_direction(joystick)
            else:
                keyboard_input = get_keyboard_input()
                wheel_speeds = get_wheel_speeds(keyboard_input, is_joystick=False)
                draw_direction(keyboard_input, is_joystick=False)

            draw_wheels(wheel_width, wheel_height, offset)
            draw_speed_arrows(offset + (wheel_width/2), offset + (wheel_height/2), wheel_speeds)

            # Update the display
            pg.display.flip()
            pg.time.delay(50)  # Add a small delay to prevent high CPU usage

    except KeyboardInterrupt:
        print("\nExiting...")

    finally:
        # Quit pg
        pg.quit()

else:
    ser = serial.Serial('COM22',
                     9600,
                     bytesize=serial.EIGHTBITS,
                     stopbits=serial.STOPBITS_ONE,
                     parity=serial.PARITY_NONE,
                     xonxoff=True,
                     timeout=1
                    )
    time.sleep(2)
    try:
        while True:
            
            # Handle events
            for event in pg.event.get():
                if event.type == pg.QUIT:
                    sys.exit()

            # Get wheel speeds from joystick or keyboard
            if joystick:
                wheel_speeds = get_wheel_speeds(joystick)
                
                if joystick.get_button(0):
                    ser.write('e\r'.encode())
                
                if joystick.get_button(1):
                    ser.write('f\r'.encode())
                    print("toggled front light!")
                    time.sleep(0.1)
                
                if joystick.get_button(2):
                    ser.write('b\r'.encode())
                    print("toggled back light!")
                    time.sleep(0.1)
            else:
                keyboard_input = get_keyboard_input()
                wheel_speeds = get_wheel_speeds(keyboard_input, is_joystick=False)
                
                # Keyboard button mappings
                keys = pg.key.get_pressed()
                if keys[pg.K_SPACE]:
                    ser.write('e\r'.encode())
                
                if keys[pg.K_f]:
                    ser.write('f\r'.encode())
                    print("toggled front light!")
                    time.sleep(0.1)

                if keys[pg.K_b]:
                    ser.write('b\r'.encode())
                    print("toggled back light!")
                    time.sleep(0.1)


            multiplier = 20
            send_speed1 = int(wheel_speeds[0]*multiplier)
            send_speed2 = int(wheel_speeds[1]*multiplier)
            send_speed3 = int(wheel_speeds[2]*multiplier)
            send_speed4 = int(wheel_speeds[3]*multiplier)

            ser.write(f'{send_speed1:05}{send_speed2:05}{send_speed3:05}{send_speed4:05}\r'.encode())
            print(f"{send_speed1:05}{send_speed2:05}{send_speed3:05}{send_speed4:05}")
            time.sleep(.1)

    except KeyboardInterrupt:
        ser.write(f'00000000000000000000\r'.encode())
        print("\nExiting...")

    finally:
        # Quit pg
        ser.write(f'00000000000000000000\r'.encode())
        pg.quit()

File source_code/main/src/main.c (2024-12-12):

#include "main.h"
#include "clock_config.h"

int main(){
    configure_clock();
    USART2_Init();
    LOG("USART2 initialized!\r\n");

    tmc_controller *drivers[4] = {&driver1, &driver2, &driver3, &driver4};

    // Define all driver values
    driver1.en_pin_number = 0;
    driver1.en_pin_port = GPIOD;
    driver1.dir_pin_number = 8;
    driver1.dir_pin_port = GPIOD;

    driver2.en_pin_number = 1;
    driver2.en_pin_port = GPIOD;
    driver2.dir_pin_number = 9;
    driver2.dir_pin_port = GPIOD;

    driver3.en_pin_number = 2;
    driver3.en_pin_port = GPIOD;
    driver3.dir_pin_number = 10;
    driver3.dir_pin_port = GPIOD;

    driver4.en_pin_number = 3;
    driver4.en_pin_port = GPIOD;
    driver4.dir_pin_number = 11;
    driver4.dir_pin_port = GPIOD;

    init_enable_pins(&drivers);
    LOG("Enable pins initialized!\r\n");

    init_direction_pins(&drivers);
    LOG("Direction pins initialized!\r\n");

    init_timers();
    LOG("Timer initialized!\r\n");
    
    // Reset speed
    for (int i = 0; i < 4; i++){
        drivers[i]->req_speed = 0;
        drivers[i]->cur_speed = 0;
    }
    LOG("Speed set to zero!\r\n");

    // INIT PHASE DONE
    LOG("Initilization phase done!\r\n");

    // MAIN LOOP
    for(;;){
        update_motors(&drivers, 8);
        
        // TODO: Integrate Timer-based clock speed
        delay(500);
    }
    return 0;
}

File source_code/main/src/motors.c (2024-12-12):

#include "motors.h"

void update_motors(tmc_controller *drivers[], int16_t acceleration){
    for (int i = 0; i < 4; i++){
        if (drivers[i]->cur_speed < drivers[i]->req_speed){
            drivers[i]->cur_speed += acceleration;
        }
        if (drivers[i]->cur_speed > drivers[i]->req_speed){
            drivers[i]->cur_speed -= acceleration;
        }
    }

    for (int i = 0; i < 4; i++){
        if (drivers[i]->cur_speed < 0){
            drivers[i]->dir_pin_port->BSRR |= GPIO_BSRR_BR0 << drivers[i]->dir_pin_number;
        } else {
            drivers[i]->dir_pin_port->BSRR |= GPIO_BSRR_BS0 << drivers[i]->dir_pin_number;
        }
    }

    TIM1->ARR = arr_from_freq(abs(driver1.cur_speed), TIM1) * 2;
    TIM1->CCR1 = arr_from_freq(abs(driver1.cur_speed), TIM1);

    // TODO: Reevaluate this calculation
    TIM9->ARR = arr_from_freq(abs(driver2.cur_speed), TIM9) * 4;
    TIM9->CCR1 = arr_from_freq(abs(driver2.cur_speed), TIM9);
    

    TIM4->ARR = arr_from_freq(abs(driver3.cur_speed), TIM4) * 2;
    TIM4->CCR1 = arr_from_freq(abs(driver3.cur_speed), TIM4);

    TIM3->ARR = arr_from_freq(abs(driver4.cur_speed), TIM3) * 2;
    TIM3->CCR1 = arr_from_freq(abs(driver4.cur_speed), TIM3);
}


void init_direction_pins(tmc_controller *drivers[]){
    // Set direction pins accordingly
    for (int i = 0; i < 4; i++){
        drivers[i]->dir_pin_port->MODER |= GPIO_MODER_MODER0_0 << (drivers[i]->dir_pin_number*2);
        drivers[i]->dir_pin_port->OTYPER &= ~(GPIO_OTYPER_OT_0 << drivers[i]->dir_pin_number);
        drivers[i]->dir_pin_port->BSRR |= GPIO_BSRR_BR0 << drivers[i]->dir_pin_number;
    }
}

void disable_all_motors(){
    tmc_controller *drivers[4] = {&driver1, &driver2, &driver3, &driver4};
    for (int i = 0; i < 4; i++){
        drivers[i]->en_pin_port->BSRR |= GPIO_BSRR_BS0 << drivers[i]->en_pin_number;
    }
}

void init_enable_pins(tmc_controller *drivers[]){
    RCC->AHB1ENR |= RCC_AHB1ENR_GPIODEN;
    for (int i = 0; i < 4; i++){
        drivers[i]->en_pin_port->MODER |= GPIO_MODER_MODER0_0 << (2 * drivers[i]->en_pin_number);
        drivers[i]->en_pin_port->OTYPER &= ~(GPIO_OTYPER_OT_0 << drivers[i]->en_pin_number);
        drivers[i]->en_pin_port->BSRR |= GPIO_BSRR_BS0 << drivers[i]->en_pin_number;
    }

    // Wait for motors to slow down after possible reset
    delay(1000000);

    for (int i = 0; i < 4; i++){
        drivers[i]->en_pin_port->BSRR |= GPIO_BSRR_BR0 << drivers[i]->en_pin_number;
    }
}

void init_timers(){
    // Enable GPIOB port 6 and set to alt func 2 (TIM4_CH1)
    RCC->AHB1ENR |= RCC_AHB1ENR_GPIOBEN;
    gpio_alt(GPIOB, 6, 2);

    // Enable GPIOB port 4 and set to alt func 2
    gpio_alt(GPIOB, 4, 2);

    // Enable GPIOA port 8 and set to alt func 1
    RCC->AHB1ENR |= RCC_AHB1ENR_GPIOAEN;
    gpio_alt(GPIOA, 8, 1);
    GPIOA->OSPEEDR |= GPIO_OSPEEDER_OSPEEDR8_1;
    GPIOA->PUPDR &= ~GPIO_PUPDR_PUPD8_Msk;

    // Enable GPIOE port 5 and set to alt func 3
    RCC->AHB1ENR |= RCC_AHB1ENR_GPIOEEN;
    gpio_alt(GPIOE, 5, 3);

    // Enable GPIOB port 3 and set to alt func 1 for back light
    gpio_alt(GPIOB, 3, 1);

    // Enable GPIOB port 10 and set to alt func 1 for front light
    gpio_alt(GPIOB, 10, 1);


    // Enable TIM4 peripheral
    RCC->APB1ENR |= RCC_APB1ENR_TIM4EN;

    // Enable TIM3 peripherals
    RCC->APB1ENR |= RCC_APB1ENR_TIM3EN;

    // Enable TIM1 peripherals
    RCC->APB2ENR |= RCC_APB2ENR_TIM1EN;

    // Enable TIM9 peripherals
    RCC->APB2ENR |= RCC_APB2ENR_TIM9EN;

    // Enable TIM2 peripherals
    RCC->APB1ENR |= RCC_APB1ENR_TIM2EN;

    // Buffer the ARR register
    TIM4->CR1 |= TIM_CR1_ARPE;

    TIM3->CR1 |= TIM_CR1_ARPE;

    TIM1->CR1 |= TIM_CR1_ARPE;
    TIM1->CR2 = 0;

    TIM9->CR1 |= TIM_CR1_ARPE;

    TIM2->CR1 |= 0;
    TIM2->CCER = 0;
    TIM2->CR1 |= TIM_CR1_ARPE;

    GPIOB->OSPEEDR |= GPIO_OSPEEDR_OSPEED3_Msk;
    GPIOB->OTYPER &= ~GPIO_OTYPER_OT3;

    // Set the prescaler and overflow values
    TIM4->PSC = 3;
    TIM4->ARR = 64000-1;
    TIM4->CCR1 = 0; // Set duty cycle initially to 0 (CCRx for channel)

    TIM3->PSC = 3;
    TIM3->ARR = 64000-1;
    TIM3->CCR1 = 0; 

    TIM1->PSC = 3;
    TIM1->ARR = 64000-1;
    TIM1->CCR1 = 0; 
    
    TIM9->PSC = 3;
    TIM9->ARR = 64000-1;
    TIM9->CCR1 = 0;

    TIM2->PSC = 0;
    TIM2->ARR = arr_from_freq(4000, TIM2);

    TIM4->CCMR1 |= (TIM_CCMR1_OC1PE | (0b110 << TIM_CCMR1_OC1M_Pos));

    TIM3->CCMR1 |= (TIM_CCMR1_OC1PE | (0b110 << TIM_CCMR1_OC1M_Pos));

    TIM1->CCMR1 &= ~TIM_CCMR1_OC1M_Msk;
    TIM1->CCMR1 |= (TIM_CCMR1_OC1PE | (0b110 << TIM_CCMR1_OC1M_Pos));

    TIM9->CCMR1 |= (TIM_CCMR1_OC1PE | (0b110 << TIM_CCMR1_OC1M_Pos));

    TIM2->CCMR1 &= ~(TIM_CCMR1_OC2M_Msk);  // Clear mode bits
    TIM2->CCMR1 |= (0b110 << TIM_CCMR1_OC2M_Pos);  // PWM mode 1
    TIM2->CCMR1 |= TIM_CCMR1_OC2PE;  // Enable preload
    TIM2->CCR2 = 0;

    TIM2->CCMR2 &= ~(TIM_CCMR2_OC3M);
    TIM2->CCMR2 |= (0b110 << TIM_CCMR2_OC3M_Pos);
    TIM2->CCMR2 |= TIM_CCMR2_OC3PE;
    TIM2->CCR3 = 0;

    // Enable Capture Compare for channel 1
    TIM4->CCER |= TIM_CCER_CC1E;
    TIM3->CCER |= TIM_CCER_CC1E;
    TIM1->CCER |= TIM_CCER_CC1E;
    TIM9->CCER |= TIM_CCER_CC1E;

    // Enable Capture Compare for channel 2,3
    TIM2->CCER |= TIM_CCER_CC2E;
    TIM2->CCER |= TIM_CCER_CC3E;
    TIM2->EGR |= TIM_EGR_UG;

    // Enable the timer and set to center-aligned mode
    TIM4->CR1 |= TIM_CR1_CMS_0 | TIM_CR1_CEN;
    TIM3->CR1 |= TIM_CR1_CMS_0 | TIM_CR1_CEN;
    TIM1->CR1 |= TIM_CR1_CMS_0 | TIM_CR1_CEN;
    TIM9->CR1 |= TIM_CR1_CMS_0 | TIM_CR1_CEN;
    TIM2->CR1 |= TIM_CR1_CMS_0 | TIM_CR1_CEN;

    //only for TIM1
    TIM1->BDTR |= TIM_BDTR_MOE;
}

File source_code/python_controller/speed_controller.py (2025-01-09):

import pygame
import serial
import time

# Initialize Pygame and the controller
pygame.init()
pygame.joystick.init()

# Check for available controllers
if pygame.joystick.get_count() == 0:
    print("No controller found.")
    exit()

# Initialize the first connected controller
controller = pygame.joystick.Joystick(0)
controller.init()

# Initialize serial communication (adjust COM port and baud rate)
ser = serial.Serial('COM9', 9600, timeout=1)  # Adjust the port and baudrate accordingly
time.sleep(2)  # Wait for the serial connection to initialize

try:
    while True:
        pygame.event.pump()  # Process event queue

        # Read the left trigger (usually axis 2)
        left_trigger_value = controller.get_axis(2)  # Change index if different for your controller
        # Map the value from -1..1 to 0..255 (if the controller reports negative values)
        left_trigger_value = int((left_trigger_value + 1) / 2 * 255)

        # Read the right trigger (usually axis 5)
        right_trigger_value = controller.get_axis(5)  # Change index if different for your controller
        # Map the value from -1..1 to 0..255 (if the controller reports negative values)
        right_trigger_value = int((right_trigger_value + 1) / 2 * 10000)

        # Send the trigger values via serial
        ser.write(f"{right_trigger_value}\r".encode())
        print(f"{right_trigger_value}\r")

        time.sleep(0.1)  # Adjust the sleep time for better responsiveness

except KeyboardInterrupt:
    print("Exiting program.")

finally:
    ser.close()
    pygame.quit()

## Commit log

2024-06-19 added first itteration of PWM code
2024-06-20 added first itteration of motor control
2024-06-20 Add files via upload
    Add Plans of the components
    [DCDC_Wandler.ipt, Fahrgestell_Baugruppe_01.0001.idw, Fahrgestell_Baugruppe_01.0008.iam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]
2024-06-20 Add files via upload
    Add Order lists for the project
    [Erste_Bestellung_Roboterfahrzeug_Mecanum_Wheel.xlsx, Zweite_Bestellung_Roboterfahrzeug_Mecanum_Wheel.xlsx, Zweite_Bestellung_Roboterfahrzeug_Mecanum_Wheel_Fert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]
2024-06-20 added schematic
2024-06-20 added working code for one stepper driver
2024-06-28 added all motor controll
2024-09-27 changed to Interrupt UART
2024-10-03 fixxed acceleration curve and cleaned up code a bit
    [main.py, main_4wheel.c]
2024-10-03 added emergency stop functionality to stm32 code
2024-10-04 updated python code to include estop button
2025-01-09 added altium source
    [Miscellaneous$.PcbLib, Miscellaneous$.SchLib, Schematic-Lib-PhilsLab.SchLib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]
